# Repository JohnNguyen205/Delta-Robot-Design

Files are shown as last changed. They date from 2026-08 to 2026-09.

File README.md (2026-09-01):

# Delta Robot Design — 3-DOF Parallel Robot Mechanical Design

> **Mechanical design project** — Ho Chi Minh City University of Technology and Education (HCMUTE).
> Complete mechanical design of a ceiling-mounted 3-DOF Delta parallel robot for high-speed pick-and-place, benchmarked against the ABB IRB 360 FlexPicker.

This repository contains the SolidWorks CAD model, the MATLAB analysis and simulation code, the finite-element (FEA) results, the machining drawings, and the electrical / control-system and machine-vision design. Every conclusion is backed by data read back from the model or the solver — no assumed figures. All figures below are taken from the design analysis, the FEA results and the control-system design.

---

## Overview

| | |
|---|---|
| Architecture | 3-DOF Delta (parallel), rotational actuators, ceiling-mounted |
| Payload | **2 kg** |
| Workspace | cylinder **Ø800 × 250 mm**, centred ≈ 925 mm below the shoulder plane |
| Pick-and-place cycle | 1.2 s (quintic trajectory) |
| Peak TCP speed / acceleration | ≈ 1875 mm/s / ≈ 1.18 g |
| Actuator | Wittenstein TPMA010S-055T gearmotor, ratio *i* = 55 |
| Structural material | Aluminium 6061-T6 (all machined parts) |
| Total mass | 122.4 kg (CAD model), ≈ 140 kg estimated real |
| Minimum factor of safety (whole robot, full workspace) | **7.1** |

---

## 1. Kinematic architecture

| Symbol | Meaning | Value |
|---|---|---|
| L₁ | upper-arm (bicep) length: shoulder axis → elbow ball line | 407.5 mm |
| L₂ | forearm length, ball-centre to ball-centre | 1000.0 mm |
| R | base joint-circle radius | 347.0 mm |
| r | moving-platform radius | 120.6 mm |
| R − r | base radius − moving-platform radius | 226.4 mm |
| φᵢ | arm azimuths | −90°, 30°, 150° |
| θᵢ | motor-angle range (elbow-down) | −45° … 70° |

<p align="center">
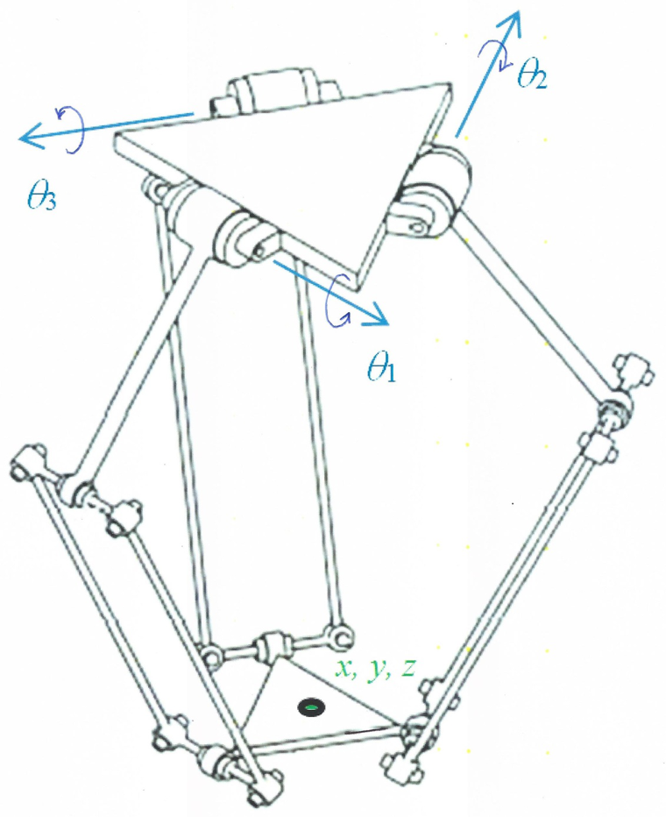
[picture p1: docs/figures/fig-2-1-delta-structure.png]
Basic structure of the RUU Delta robot
  
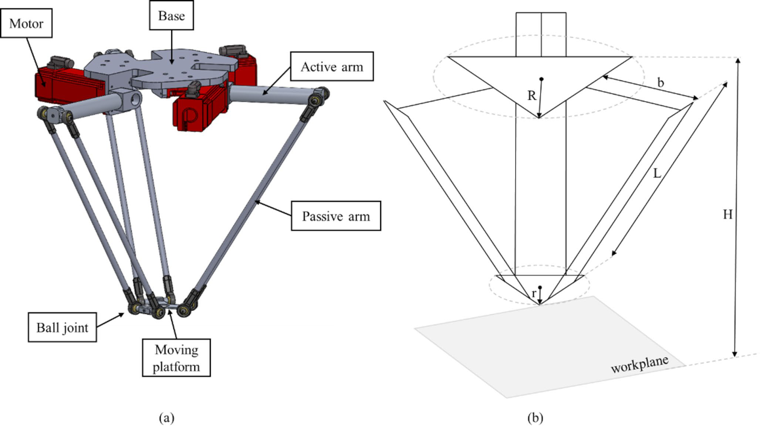
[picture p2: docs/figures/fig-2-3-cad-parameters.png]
CAD model and general geometric parameters
  
</p>

<p align="center"><b>Fig. 2.1 / 2.3.</b> Basic structure of the three-arm RUU Delta robot (left); CAD model and the general geometric parameters R, r, L, b, H (right).</p>

### Geometric model

Each arm $i$ has a fixed azimuth $\phi_i$; the three arms sit at −90°, 30° and 150°. Writing $c_i=\cos\phi_i$ and $s_i=\sin\phi_i$, and measuring the motor angle $\theta_i$ downward from the shoulder plane, the base joint, the platform joint and the elbow of arm $i$ are

$$\mathbf{B}_i = R\,(c_i,\ s_i,\ 0)$$

$$\mathbf{P}_i = \mathbf{P} + r\,(c_i,\ s_i,\ 0)$$

$$\mathbf{E}_i = \mathbf{B}_i + L_1\,(c_i\cos\theta_i,\ s_i\cos\theta_i,\ -\sin\theta_i)$$

The rigid forearm gives one closure equation per arm:

$$\lVert \mathbf{E}_i - \mathbf{P}_i \rVert = L_2$$

### Inverse kinematics (closed form)

For a target $\mathbf{P}=(x,y,z)$ the closure equation of each arm reduces to a single equation in $\theta_i$:

$$E_i\sin\theta_i + F_i\cos\theta_i + G_i = 0$$

$$u_i = x\,c_i + y\,s_i - (R-r), \qquad w_i = -x\,s_i + y\,c_i$$

$$E_i = 2 L_1 z, \qquad F_i = -2 L_1 u_i, \qquad G_i = L_1^2 + u_i^2 + w_i^2 + z^2 - L_2^2$$

With $\rho_i=\sqrt{E_i^2+F_i^2}$ and $\psi_i=\mathrm{atan2}(F_i,\ E_i)$:

$$\theta_i = \arcsin\!\left(\frac{-G_i}{\rho_i}\right) - \psi_i$$

taking the elbow-down root inside the range −45° … 70°. A real solution exists only if $|G_i| \le \rho_i$; otherwise $\mathbf{P}$ lies outside the reachable workspace.

### Forward kinematics

Given the three angles, shift each elbow to a virtual centre $\mathbf{C}_i = \mathbf{E}_i - r\,(c_i,\ s_i,\ 0)$. The platform centre $\mathbf{P}$ is the intersection (trilateration) of three spheres of radius $L_2$ centred at $\mathbf{C}_1,\mathbf{C}_2,\mathbf{C}_3$, keeping the lower-$z$ root. Round-trip check: the error $\lVert \mathbf{P} - \mathrm{FK}(\mathrm{IK}(\mathbf{P})) \rVert$ stays below $6.2\times10^{-13}$ mm over 3000 points (see §2).

### Velocity Jacobian and singularity

Differentiating the three closure equations gives

$$\mathbf{A}\,\dot{\mathbf{P}} = \mathbf{B}\,\dot{\boldsymbol{\theta}}, \qquad \dot{\mathbf{P}} = \mathbf{J}\,\dot{\boldsymbol{\theta}}, \qquad \mathbf{J} = \mathbf{A}^{-1}\mathbf{B}$$

Row $i$ of $\mathbf{A}$ is the forearm direction $(\mathbf{E}_i-\mathbf{P}_i)^{T}$, and $\mathbf{B}$ is diagonal with

$$B_{ii} = L_1\,(\mathbf{E}_i-\mathbf{P}_i)^{T}\,\hat{\mathbf{v}}_i, \qquad \hat{\mathbf{v}}_i = (-c_i\sin\theta_i,\ -s_i\sin\theta_i,\ -\cos\theta_i)$$

Here $\det\mathbf{A}=0$ marks a parallel (Type II) singularity, $\det\mathbf{B}=0$ a boundary (Type I) singularity, and the condition number $\kappa(\mathbf{J})$ measures how close a pose is to one. Over the target workspace $\kappa(\mathbf{J}) \le 2.75$ with no singular points.

## 2. Kinematics verification

The inverse and forward kinematics were implemented independently and cross-checked:

- Round-trip error ‖P − FK(IK(P))‖ ≤ **6.2 × 10⁻¹³ mm** over 3000 sample points.
- Reachable radius 650 mm at z = −925 mm (requirement: 400 mm).
- Jacobian: **no singular points** inside the workspace; condition number κ(J) max 2.75, average 2.13; minimum forearm–bicep transmission angle 49.8°.

<p align="center">
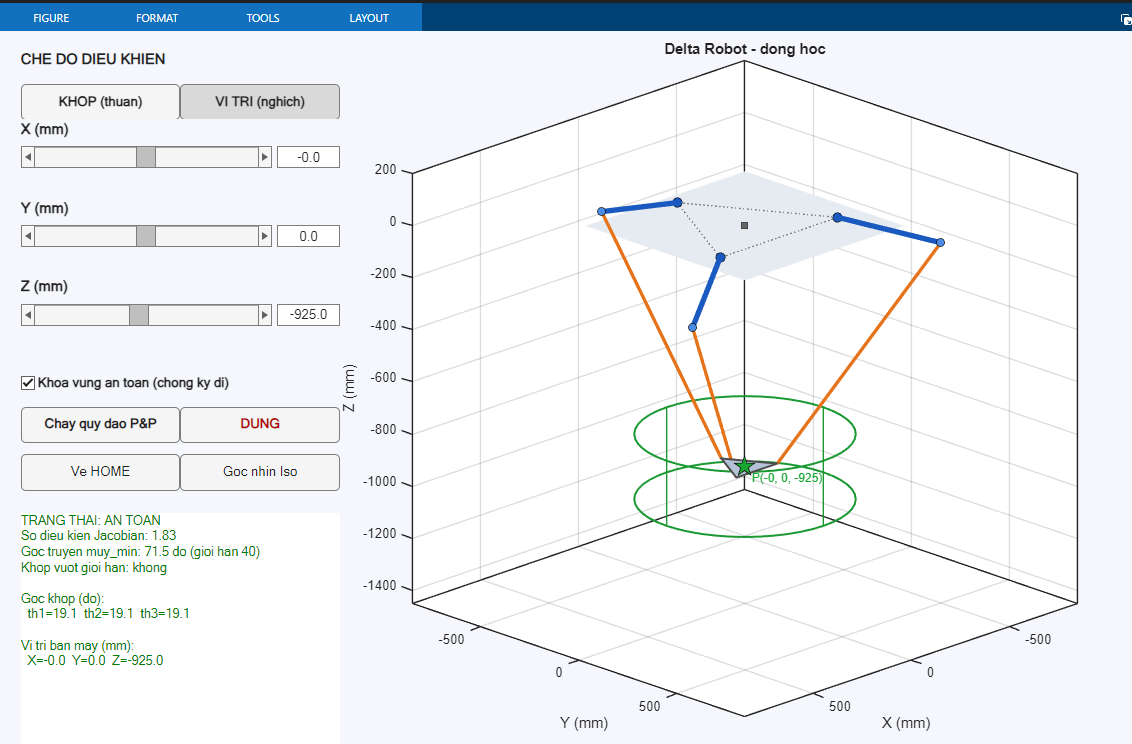
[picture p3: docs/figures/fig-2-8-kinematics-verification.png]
Simulation check of the kinematic solution
  
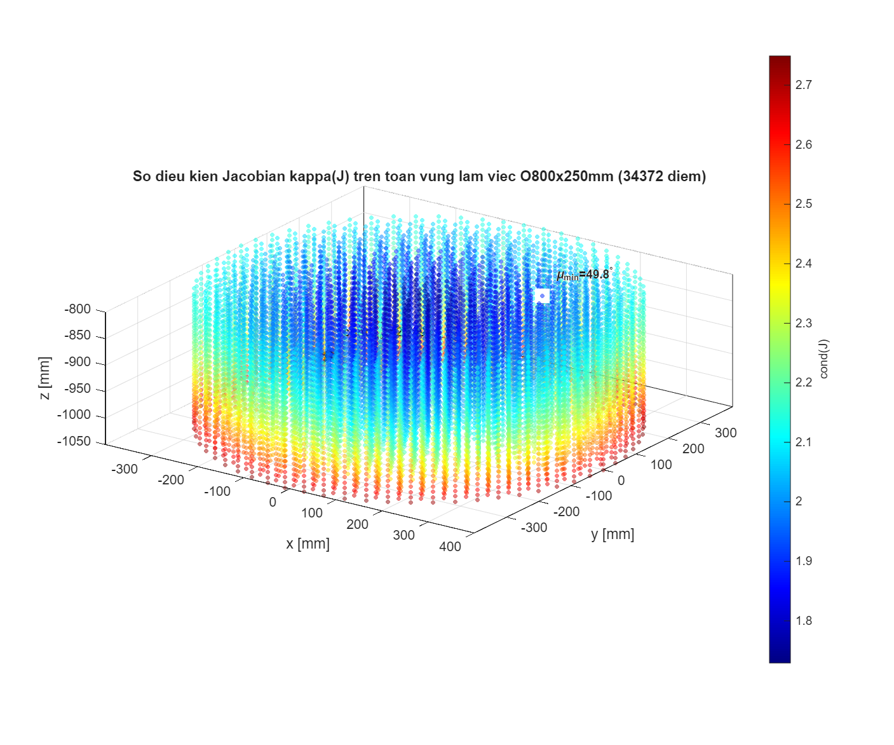
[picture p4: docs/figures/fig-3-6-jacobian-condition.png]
Jacobian condition number and transmission angle
  
</p>

<p align="center"><b>Fig. 2.8 / 3.6.</b> Simulation check of the kinematic computation (left); distribution of the Jacobian condition number and the force-transmission angle over the working region (right).</p>

<p align="center">
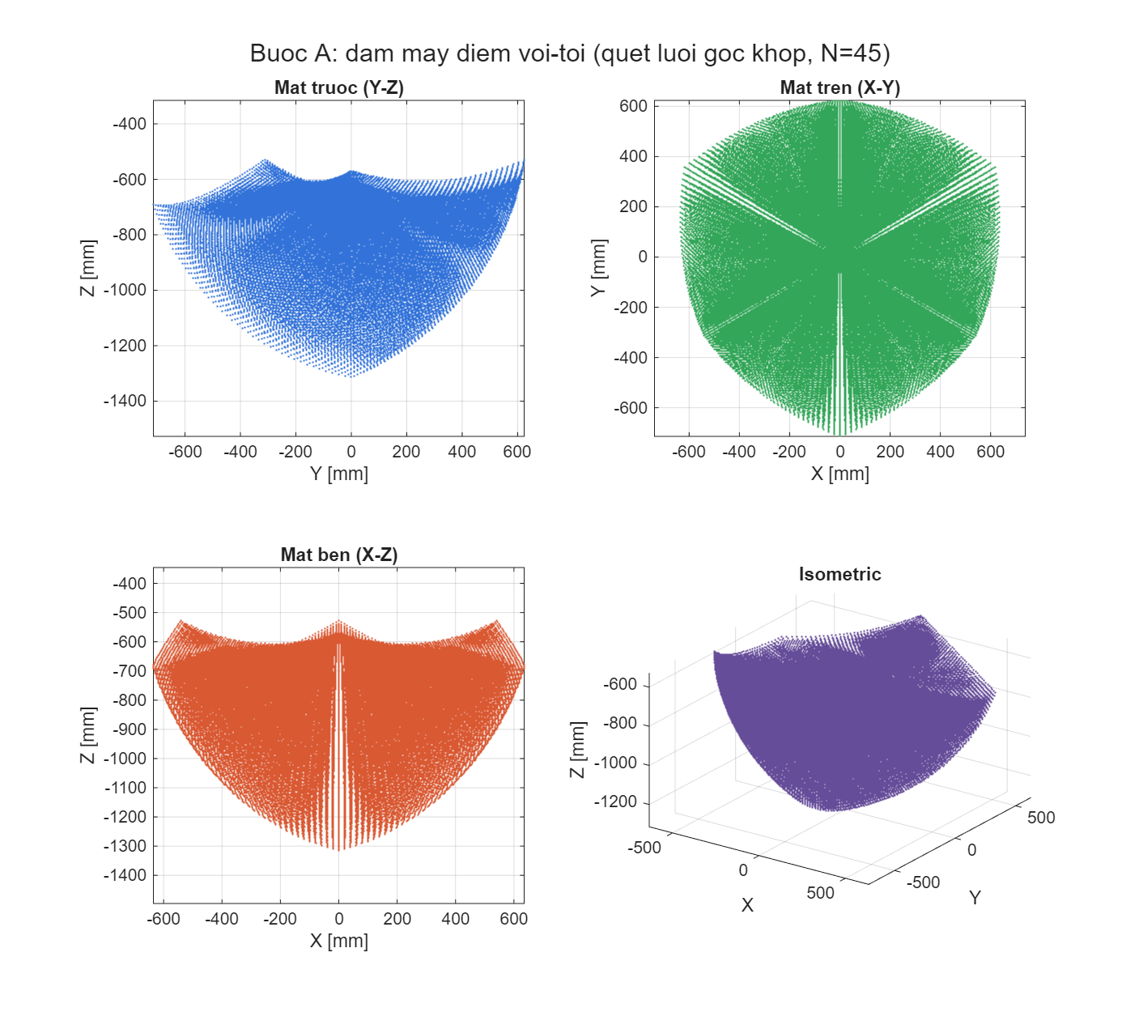
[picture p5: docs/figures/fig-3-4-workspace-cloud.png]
Workspace point cloud
  
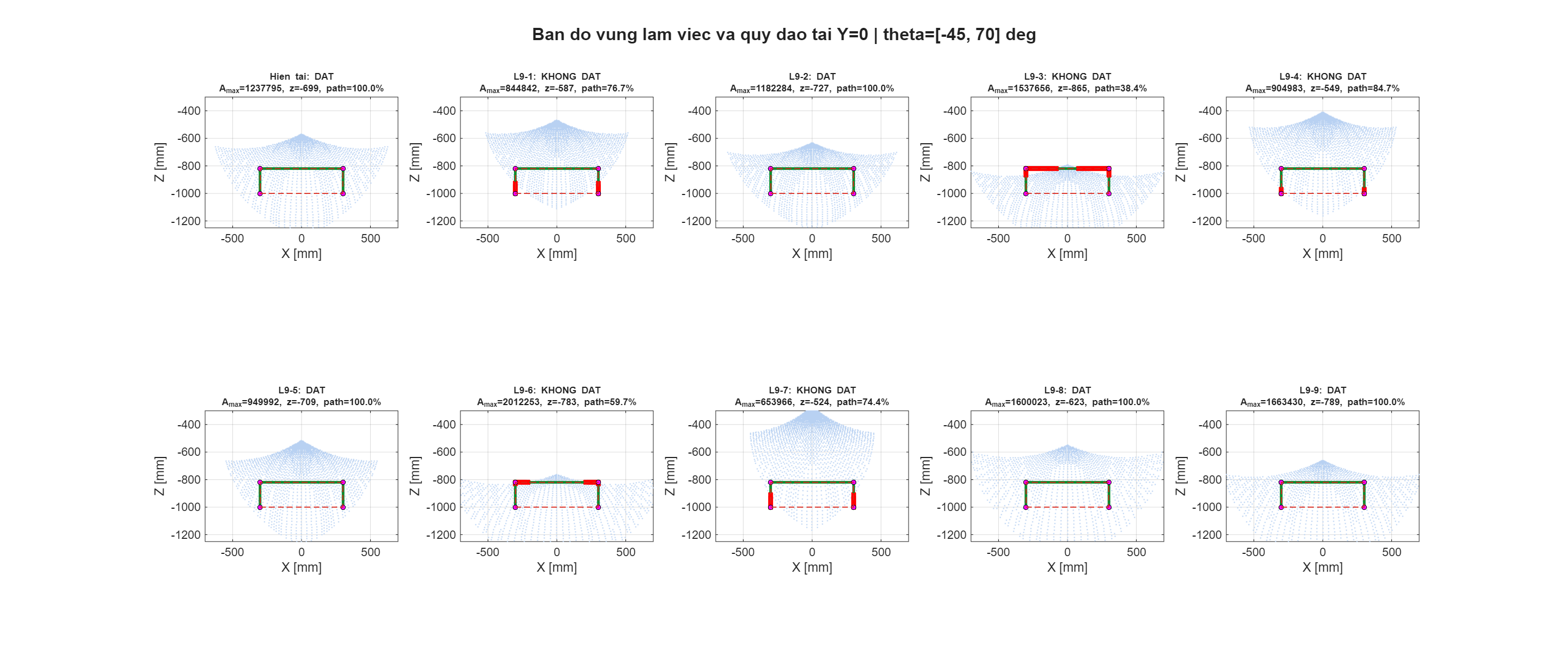
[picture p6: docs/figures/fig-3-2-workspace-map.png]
Workspace map at y = 0 with trajectory check
  
</p>

<p align="center"><b>Fig. 3.4 / 3.2.</b> Workspace point cloud from the three joint-angle sweep (left); workspace map at y = 0 with the pick-and-place trajectory check (right).</p>

## 3. Motion & trajectory

The pick-and-place cycle is planned as a fifth-order (quintic) polynomial and the joint kinematics are checked against their bounds.

<p align="center">
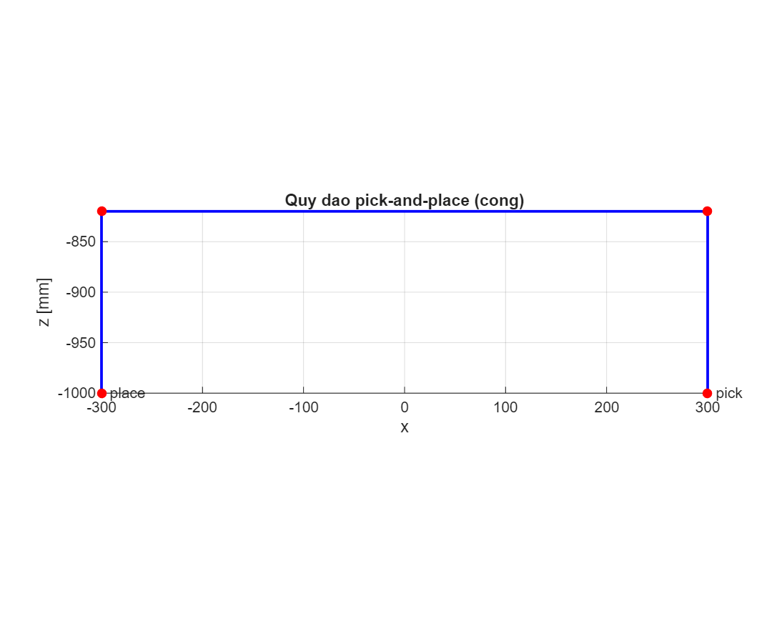
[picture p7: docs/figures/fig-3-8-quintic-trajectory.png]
Quintic pick-and-place trajectory
  
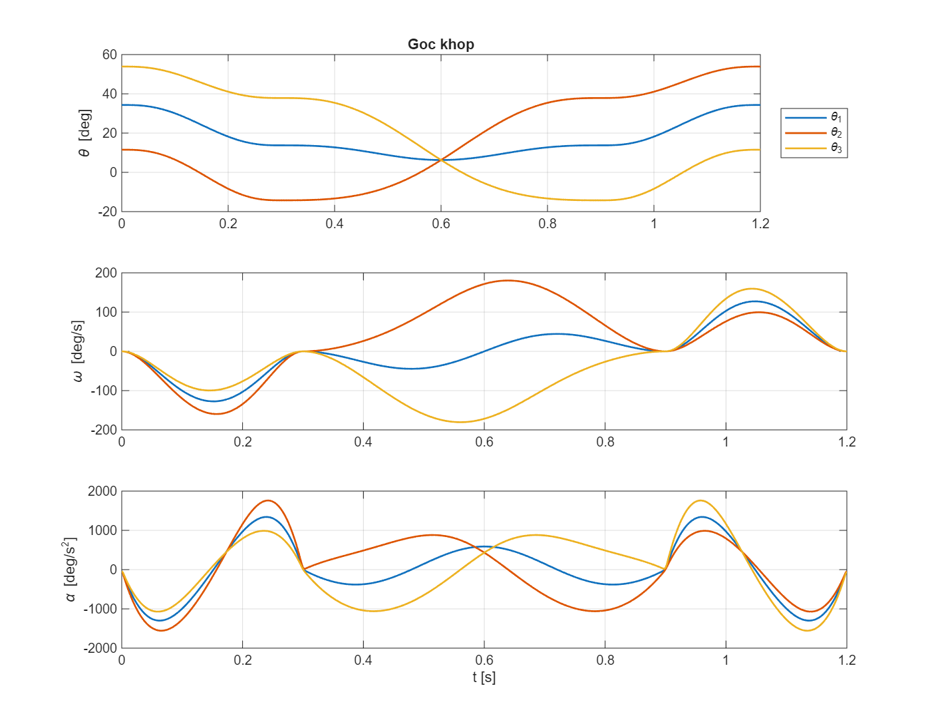
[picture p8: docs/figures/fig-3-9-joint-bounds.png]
Joint angle, velocity and acceleration bounds
  
</p>

<p align="center"><b>Fig. 3.8 / 3.9.</b> Pick-and-place trajectory interpolated with a fifth-order polynomial (left); joint angle, angular-velocity and angular-acceleration bounds along the trajectory (right). Peak joint speed 30.1 rpm.</p>

## 4. Force & dynamic analysis

Forearm links are solved as two-force members; joint torques are obtained through the Jacobian. Loads are swept over the whole workspace (centre + 24 edge points + 4 waypoints × 26 peak-acceleration directions) and the worst case is retained.

| Quantity | Nominal (centre pose) | Worst case (workspace edge, R400 / z−1050) |
|---|---|---|
| End-effector force F_ee | 175.8 N | 176.1 N |
| Forearm-pair force | 122.7 N (61.3 N per rod) | **182.4 N** (× 1.49) |
| Bicep bending moment | ≈ 50 N·m | **74.3 N·m** (× 1.49) |
| Platform joint torque τ | 48.4 N·m | — |
| Jacobian condition number | — | 2.75 (no singularity) |

<p align="center">
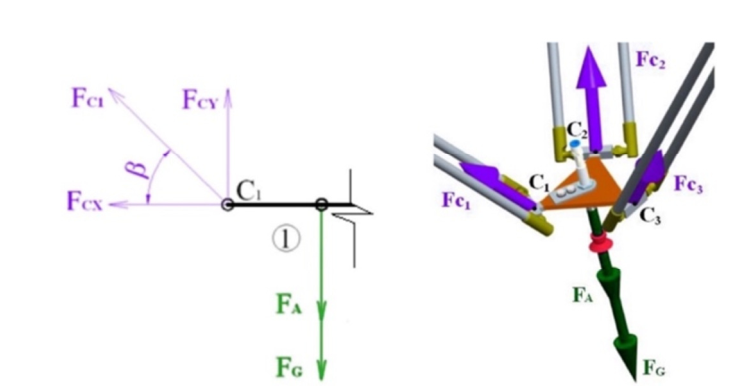
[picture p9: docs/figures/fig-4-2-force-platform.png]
Force diagram at the moving platform
  
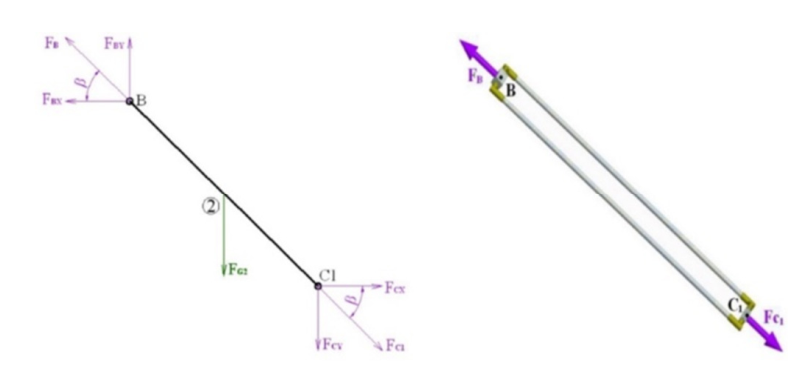
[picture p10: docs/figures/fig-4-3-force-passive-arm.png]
Force diagram of the passive arm
  
</p>

<p align="center"><b>Fig. 4.2 / 4.3.</b> Force diagram at the moving platform (left) and in the passive (long) arm (right).</p>

<p align="center">
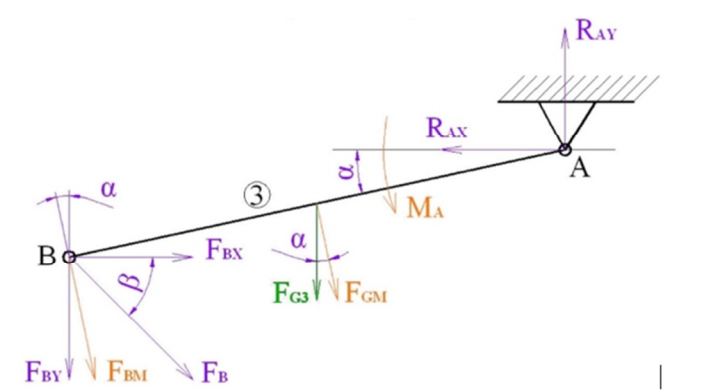
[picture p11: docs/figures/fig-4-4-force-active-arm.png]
Force diagram of the active arm
  
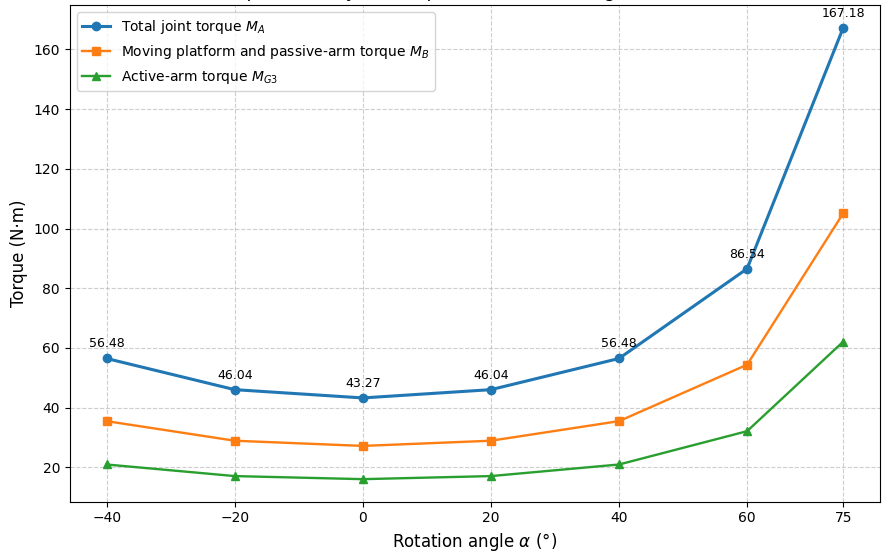
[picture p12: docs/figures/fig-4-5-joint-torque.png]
Active-joint torque versus tilt angle
  
</p>

<p align="center"><b>Fig. 4.4 / 4.5.</b> Force diagram of the active arm (left); torque at the active joint versus tilt angle α (right).</p>

## 5. Actuator selection

The required joint torque is split into static and dynamic terms and multiplied by a 1.5 safety factor (per the advisor's method), including the bicep weight and inertia (6.9 kg, from CAD) and the reflected rotor inertia *J*₍mot₎·*i*²:

| Criterion | Result | Margin |
|---|---|---|
| Required torque M_yc = (M_static 35.8 + M_dynamic 55.0) × 1.5 | 136.3 N·m ≤ T2B 230 N·m | **1.69 ×** |
| RMS torque M_rms | 53.4 N·m ≤ 110 N·m | **2.06 ×** |
| Joint speed | 30.1 rpm ≤ 88 rpm | pass |

The initially considered TPM-010S-061T (T2B 80 N·m) is rejected — M_yc 112.5 N·m > 80 N·m. The high-torque **TPMA010S-055T** passes all three criteria.

<p align="center">
  Selected gearmotor TPMA010S-055T
</p>

<p align="center"><b>Fig. 4.6.</b> Selected gearmotor with reduction unit — Wittenstein TPMA010S-055T.</p>

## 6. Structure & materials

- **All machined parts: aluminium 6061-T6.** The base was first designed in ASTM A36 steel but was too heavy, so all three base blocks were reassigned to 6061-T6 (−128.8 kg).
- Forearm connecting rods: carbon fibre. Ball-joint rod ends (`60645K471`): alloy steel.
- The base plate (`DR-001`) is split into three separate fabrication blocks — mounting plate, welded frame, and hanging lid — bolted/welded together.
- Part numbering: `DR-000` main assembly, `DR-001…DR-007` machined parts; purchased parts keep their vendor names.

<p align="center">
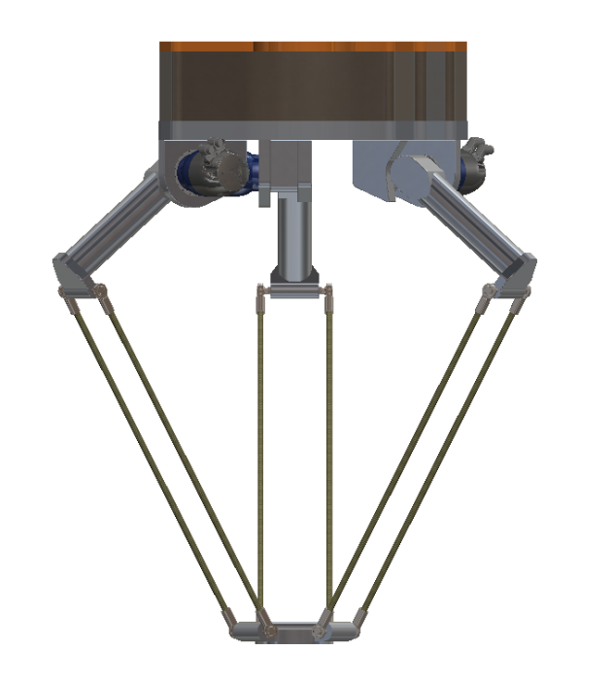
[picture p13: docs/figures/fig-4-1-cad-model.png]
3D design model in SolidWorks
  
</p>

<p align="center"><b>Fig. 4.1.</b> 3D design model in SolidWorks.</p>

## 7. Vacuum gripper (end effector)

The end effector is a vacuum gripper at the platform centre, facing down, that
picks parts off the conveyor and sorts them by shape (triangle / circle /
square). The cup, valve, tubing and sensor mass is **not** part of the 2 kg
payload — it is added to the dynamic model once the hardware is fixed; the grip
is sized against the 2 kg payload alone.

Required suction force (weight + lift inertia, with a pull-off safety factor):

$$F_s = k\,m\,(g + a_z)$$

Total cup area and minimum working vacuum for $n$ round cups of diameter $d$ and
effective efficiency $\eta$:

$$S = n\,\pi\,\frac{d^{2}}{4}, \qquad p_\text{req} = \frac{F_s}{\eta\,S}, \qquad F_\text{cap} = \eta\,p_\text{max}\,S \ge F_s$$

With $k = 2.0$, $m = 2.0$ kg, $g = 9.81$, $a_z = 11.58$ m/s², $n = 2$ cups,
$d = 40$ mm, $\eta = 0.70$:

| Quantity | Value |
|---|---|
| Required suction force $F_s$ | 85.56 N |
| Total cup area $S$ | 2.513 × 10⁻³ m² |
| Minimum vacuum $p_\text{req}$ | 48.7 kPa |
| Holding force at $p_\text{max}=60$ kPa | 105.6 N ≥ 85.56 N ✓ |

Preliminary cup layout by shape: triangle 2 × Ø40 (or 4 × Ø30), circle 2 × Ø40
symmetric about the centre, square 4 × Ø30.

<p align="center">
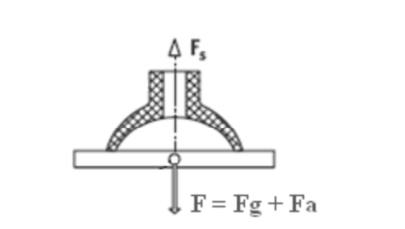
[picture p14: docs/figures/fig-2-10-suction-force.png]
Force diagram of a part lifted vertically by a vacuum cup
  
</p>

<p align="center"><b>Fig. 2.10.</b> Forces on a part lifted vertically by the vacuum cup: suction force F<sub>s</sub> up, weight + lift inertia F = F<sub>g</sub> + F<sub>a</sub> down.</p>

## 8. Structural validation (FEA)

SolidWorks Simulation, static studies on the load-bearing parts with the peak dynamic loads from §4, including a mesh-convergence sweep and a full-workspace multi-pose sweep.

| Part | von Mises (worst pose) | Factor of safety |
|---|---|---|
| DR-006 Elbow clevis | 38.8 MPa | **7.1** (governing) |
| DR-005-2 Upper-arm link | — | 43.5 |
| DR-007 Moving platform | — | 14.7 |
| DR-001-1 Base plate (aluminium) | — | ≈ 1268 |
| DR-001-3 Ceiling lid (aluminium) | — | ≈ 72 |

<p align="center">
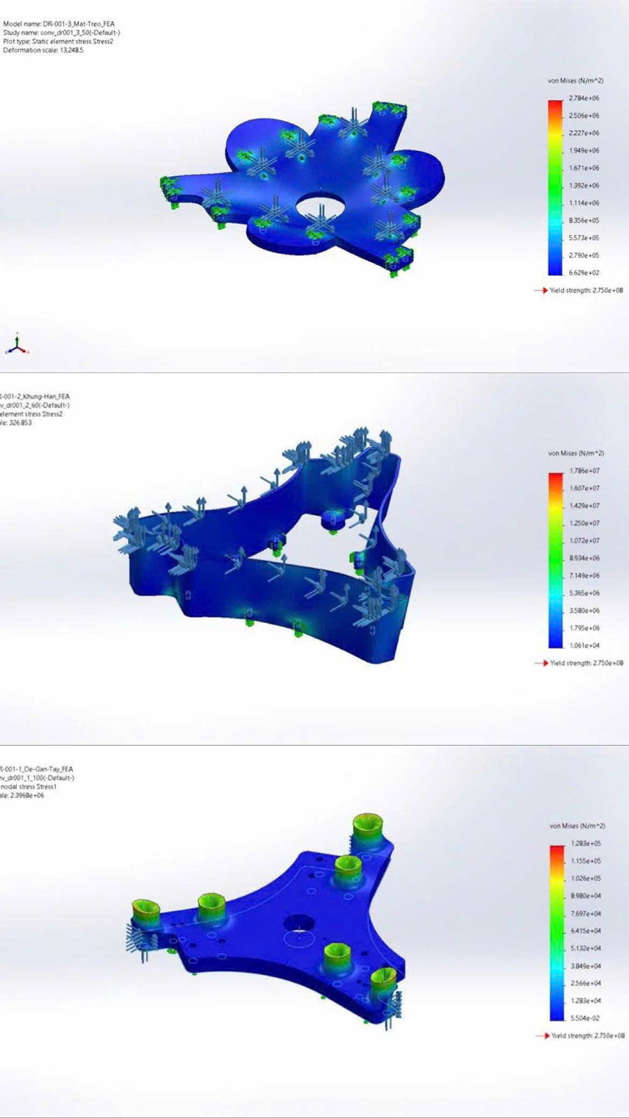
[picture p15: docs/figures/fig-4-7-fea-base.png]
von Mises stress on the base blocks
  
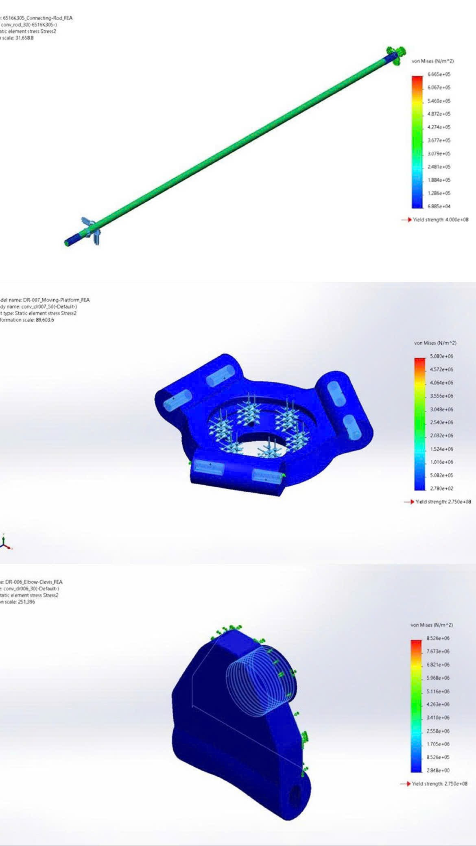
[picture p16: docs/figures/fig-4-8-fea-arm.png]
von Mises stress on the arm parts and rod
  
</p>

<p align="center"><b>Fig. 4.7 / 4.8.</b> von Mises stress — DR-001-3, DR-001-2 and DR-001-1 (left); DR-006, DR-007 and connecting rod 6516K305 (right). The whole-robot minimum factor of safety over the entire workspace is <b>7.1</b>.</p>

---

## 9. Electrical & control system

The control system is a Siemens motion-control stack. An industrial PC (**SIMATIC IPC**) runs the vision pipeline and streams pick coordinates over **PROFINET** to a **SIMOTION D** motion controller, which carries a built-in Delta technology object (synchronous three-axis interpolation). SIMOTION drives three **SINAMICS S120** motor modules over **DRIVE-CLiQ**, one per arm, each powering a **TPMA010S-055T** gearmotor with incremental-encoder feedback. The three motor modules share one Active Line Module (common DC bus), so braking energy is recovered between axes.

Safety is a hardwired chain independent of the main controller: an E-Stop / limit-switch loop (Siemens 3RG40 / SIRIUS 3SK) triggers **STO** (Safe Torque Off, IEC 61800-5-2) directly on the SINAMICS drives through a SIRIUS 3SK safety relay.

Servo power is **320 V AC** (per the TPMA010S-055T datasheet); SIMOTION, the SIRIUS relay and the IPC share a **24 V DC** control supply (IEC 61131-2); the camera is powered over its GigE link. DC-supply and fuse ratings, and the conveyor branch, are not yet dimensioned.

| Link | Bus / standard | Purpose |
|---|---|---|
| Camera (Basler acA1300-30gc) ↔ SIMATIC IPC | GigE Vision (Ethernet ≤ 1000 Mbps) | raw high-speed image transfer |
| SIMATIC IPC ↔ SIMOTION D | PROFINET IO (real-time industrial Ethernet) | pick coordinates / status |
| SIMOTION D ↔ SINAMICS S120 (×3) | DRIVE-CLiQ (internal bus, same rack) | servo control, real-time encoder feedback |
| SIRIUS 3SK ↔ SINAMICS S120 | STO (IEC 61800-5-2, hardwired) | controller-independent safe torque off |
| E-Stop / limit switch (3RG40) ↔ SIRIUS 3SK | hardwired digital I/O | safety signal |
| SINAMICS S120 ↔ TPMA010S-055T (×3) | power cable + incremental-encoder cable | servo power, position feedback |
| AC mains ↔ SINAMICS S120 | 320 V AC | drive power |
| DC supply ↔ IPC / SIMOTION / SIRIUS | 24 V DC | control power |

<p align="center">
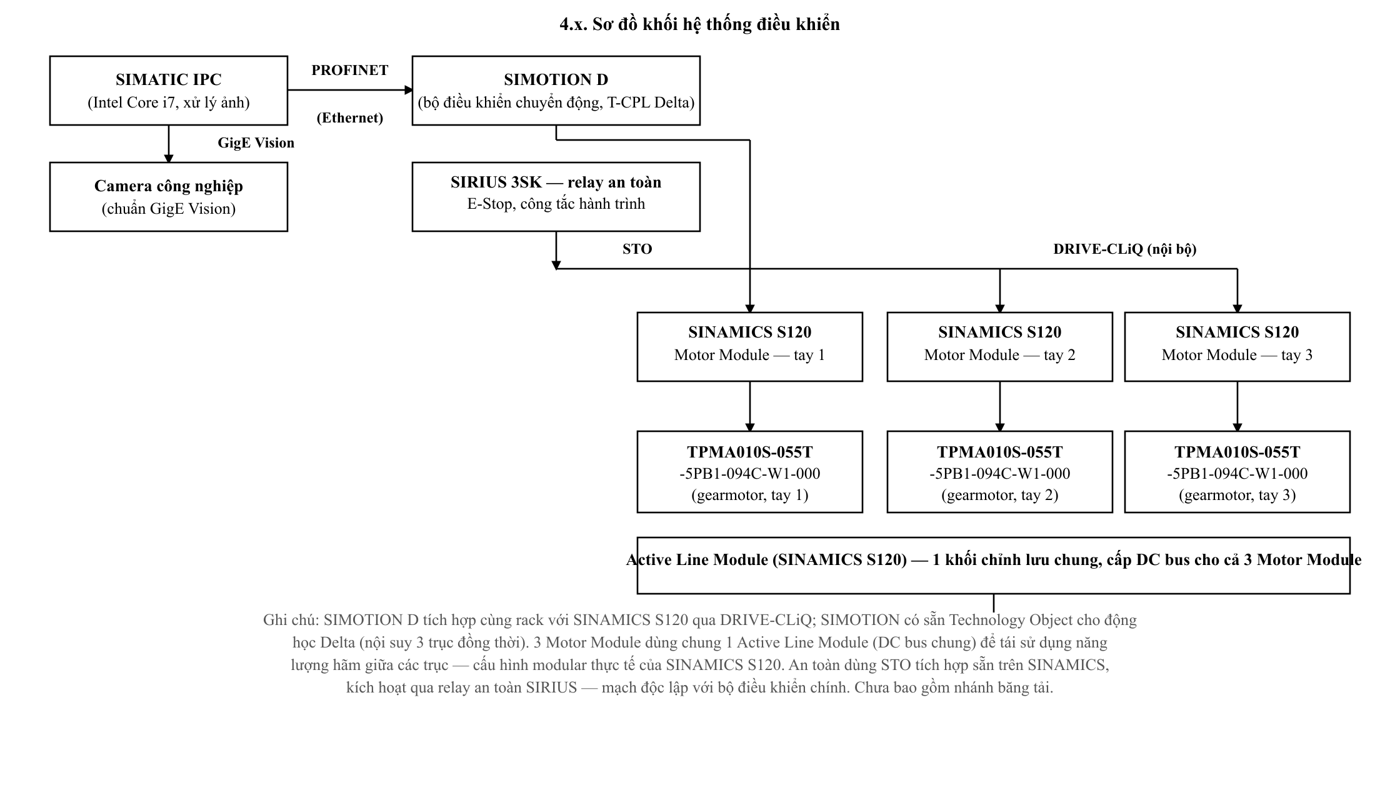
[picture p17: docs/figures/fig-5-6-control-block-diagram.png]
Control system block diagram
  
</p>

<p align="center"><b>Fig. 5.6.</b> Control-system block diagram — vision IPC, SIMOTION D motion controller, three SINAMICS S120 drives on a shared DC bus, and the SIRIUS / STO safety branch.</p>

<p align="center">
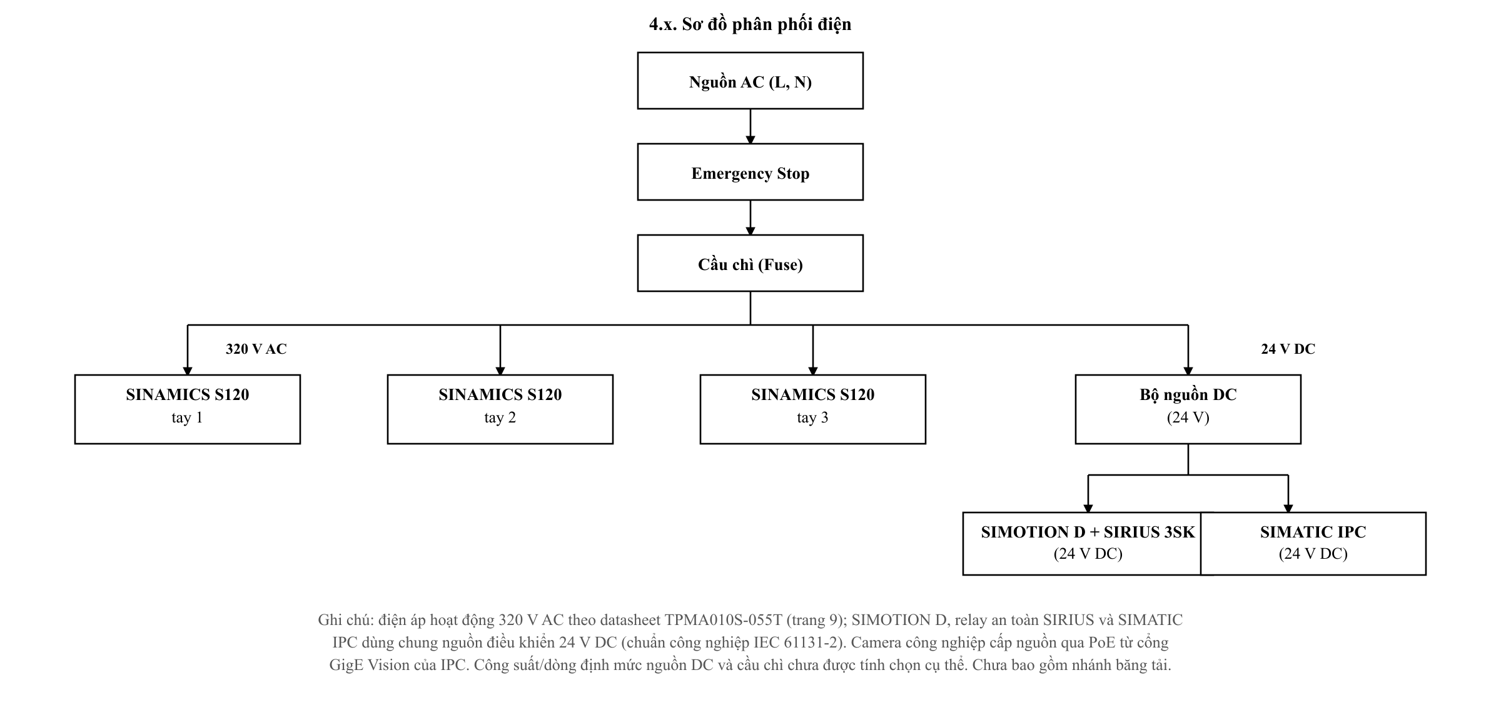
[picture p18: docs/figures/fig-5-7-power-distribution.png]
Power distribution diagram
  
</p>

<p align="center"><b>Fig. 5.7.</b> Power distribution — AC mains through E-Stop and fuse to 320 V AC for the three drives and a 24 V DC control supply for the IPC, SIMOTION D and SIRIUS relay.</p>

## 10. Machine vision (image processing)

Each frame is converted from BGR to HSV, then two branches run in parallel. The **shape** branch performs corner / blob detection and template matching, classifying every object as circle, square or triangle. The **colour** branch applies fixed HSV thresholds for red, green and yellow and detects blobs by area. The two results are merged into a `(colour, shape)` label per object, and the corresponding pick coordinate is sent to the IPC.

| Colour | Lower (H, S, V) | Upper (H, S, V) |
|---|---|---|
| Red | (173, 0, 0) | (255, 255, 255) |
| Yellow | (18, 0, 76) | (36, 255, 255) |
| Green | (58, 155, 114) | (85, 255, 255) |

On a synthetic test image of 9 objects (3 shapes × 3 colours) on a dark, conveyor-like background, the algorithm returned the correct `(colour, shape)` label for **all 9**, and the red threshold isolated a clean binary mask containing only the 3 red objects — confirming the pipeline before integration with a real camera.

A pixel coordinate (u, v) is mapped to a physical pick point (X, Y) through three coordinate frames — camera {C}, robot base {B} and conveyor {W} — by a linear calibration.

<p align="center">
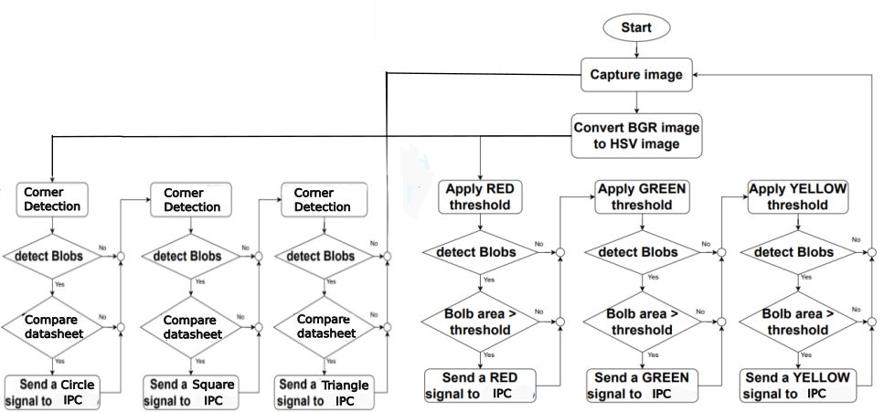
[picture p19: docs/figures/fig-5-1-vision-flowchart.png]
Colour and shape recognition flowchart
  
</p>

<p align="center"><b>Fig. 5.1.</b> Colour- and shape-recognition algorithm: parallel shape branch (corner / blob detection, template match → circle / square / triangle) and colour branch (HSV threshold → red / green / yellow, blob by area).</p>

<p align="center">
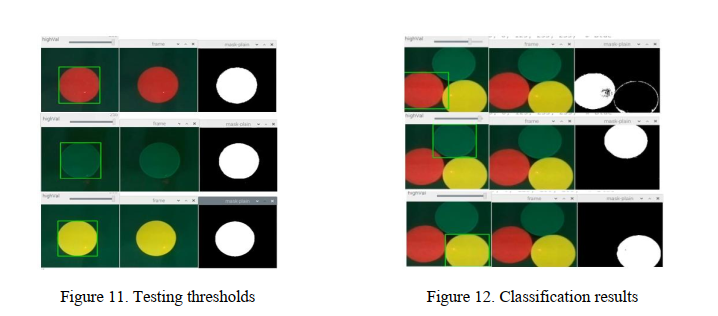
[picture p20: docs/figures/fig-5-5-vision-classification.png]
Threshold tuning and multi-object classification result
  
</p>

<p align="center"><b>Fig. 5.5.</b> Threshold tuning per colour (left) and the resulting multi-object classification on the simulated conveyor image (right).</p>

---

## 11. Design report — chapters

| Chapter | Title | What it covers |
|---|---|---|
| **1** | Overview | Motivation; state of the art of Delta robots; general and specific objectives; research object and scope; research method; report outline. |
| **2** | Theoretical basis | Delta structure and working principle; geometric model and coordinate frames; kinematic foundations — degrees of freedom, geometric parameters, per-limb closed-loop equations, forward kinematics, inverse kinematics, model-consistency check; basis for the vacuum-gripper design — joint layout and suction-cup arrangement, suction force and vacuum pressure. |
| **3** | Workspace computation & simulation | Objectives, scope and input data; the L9 survey parameter set and the test trajectory; point-density workspace simulation — joint-space sweep, volume and largest-cross-section estimate; verification of the target Ø800 × 250 mm cylinder, of the pick-and-place trajectory, and of the joint velocity / acceleration bounds. |
| **4** | Load analysis, material & drivetrain selection | Material selection; part masses from CAD; load data and force-distribution model; internal-force analysis of the links — free-body model, axial forces, motor–gearbox selection; FEA strength check of the main load-bearing parts; overall strength summary versus requirements. |
| **5** | Electrical & control system design | Machine-vision system — colour/shape recognition algorithm and test results on sample images; camera–robot–conveyor coordinate transforms; control-board architecture. |
| **6** | Conclusion & future work | Results, limitations of the work, and development directions. |

---

<sub>The full design report, third-party vendor CAD and reference papers are not included in this repository (see `.gitignore`). All rights reserved; please cite if reused. © JohnNguyen205, HCMUTE.</sub>

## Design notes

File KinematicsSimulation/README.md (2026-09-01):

# Kinematics simulation — Delta Robot (MATLAB R2025a)

Self-contained inverse/forward kinematics, workspace, singularity and trajectory
study for the 3-DOF Delta robot. All kinematic constants come from `params.m`
(single source) and must stay in sync with the CAD design values.

## Contents

| File | Purpose |
|---|---|
| `params.m` | kinematic constants: `L1=407.5`, `L2=1000.0`, `R=347.0`, `r=120.6` mm, `phi=(-90,30,150)°` |
| `delta_ik.m` / `delta_fk.m` | inverse (P → θ, closed form) / forward (θ → P, trilateration) kinematics |
| `delta_jacobian.m` | velocity Jacobian `J = A⁻¹B`, condition number, transmission angle, Type I/II singularity flags |
| `p3_workspace.m` | joint-sweep workspace point cloud + volume / largest cross-section |
| `p4_singularity.m`, `p4b_cond3d.m` | κ(J) map over the working region |
| `p5_trajectory.m` | quintic pick-and-place trajectory, joint bound check |
| `p6_animate.m`, `delta_gui.m`, `deltaviz.m` | animation and interactive viewer |
| `verify_target_workspace.m` | check the Ø800 × 250 mm target cylinder is fully reachable |
| `THUYETMINH_DONGHOC_CHITIET.md`, `TINHTOAN_DONGHOC_CHITIET.md` | detailed derivation and worked calculation (Vietnamese) |
| `KETQUA_DONGHOC.md` | phase-by-phase results log |
| `figs/`, `out/` | generated figures / logs / `.mat` |

## How to run

```
matlab -batch "cd('<repo>/KinematicsSimulation'); test_p1_ik_fk"
matlab -batch "cd('<repo>/KinematicsSimulation'); p3_workspace"
matlab -batch "cd('<repo>/KinematicsSimulation'); p5_trajectory"
```

`delta_gui.m` renders only on the live MATLAB desktop, not in `-batch`.

## Key results

- FK(IK(P)) round-trip error ≤ 6.2 × 10⁻¹³ mm over 3000 points.
- Reachable radius 650 mm at z = −925 mm (requirement 400 mm).
- Jacobian: no singular points in the workspace; κ(J) max 2.75, avg 2.13;
  minimum forearm–bicep transmission angle 49.8°.

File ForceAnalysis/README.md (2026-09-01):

# Force analysis & actuator selection — Delta Robot (payload 2 kg)

Force study that (1) produces the **real loads** used as FEA input and
(2) **checks the gearmotor choice** by the static + dynamic × safety-factor
moment method (advisor's format): forearm links solved as two-force members,
joint torques through the Jacobian, motor sizing including bicep weight/inertia
(6.9 kg from CAD) and reflected rotor inertia `J_mot·i²`, safety factor 1.5.

## Contents

| File | Purpose |
|---|---|
| `params.m`, `delta_ik.m`, `delta_jacobian.m` | kinematic constants + IK/Jacobian (copy kept in sync with `../KinematicsSimulation`) |
| `force_analysis.m` | forearm forces + static/dynamic joint moments + motor–gearbox check |
| `force_poses.m` | multi-pose load sweep (centre + 24 workspace-edge points + waypoints × peak-accel dirs), worst case retained |
| `force_diagrams.m` | free-body diagram + N/Q/M internal-force diagrams |
| `moment_angle_sweep.m` | joint moment vs tilt angle, CSV/MAT + peak plot |
| `fea_load_params.m` | exports the peak loads consumed by `../FEA_Simulation` |
| `ThuyetMinh_ChonDongCo.md` | detailed motor-selection write-up (Vietnamese) |
| `figs/`, `out/` | result figures / logs / `.mat` |

## How to run

```
matlab -batch "cd('<repo>/ForceAnalysis'); force_analysis"
matlab -batch "cd('<repo>/ForceAnalysis'); force_poses"
matlab -batch "cd('<repo>/ForceAnalysis'); force_diagrams"
```

## Key results

| Quantity | Nominal (centre) | Worst case (edge, R400 / z−1050) |
|---|---|---|
| End-effector force F_ee | 175.8 N | 176.1 N |
| Forearm-pair force | 122.7 N (61.3 N/rod) | 182.4 N (× 1.49) |
| Bicep bending moment | ≈ 50 N·m | 74.3 N·m (× 1.49) |
| Jacobian condition number | — | 2.75 (no singularity) |

Motor check (TPMA010S-055T, i = 55): required M_yc = (35.8 + 55.0) × 1.5 =
136.3 N·m ≤ T2B 230 (1.69×); M_rms 53.4 ≤ 110 (2.06×); 30.1 rpm ≤ 88 rpm —
all pass. The initially considered TPM-010S-061T (T2B 80 N·m) fails.

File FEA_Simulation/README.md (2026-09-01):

# Structural simulation (FEA) — Delta Robot

SolidWorks Simulation static studies on the load-bearing parts, driven over COM
from PowerShell. Loads are the peak dynamic forces from `../ForceAnalysis`
(payload 2 kg). Each study includes a mesh-convergence sweep; a second pass
applies the worst-case multi-pose loads over the whole workspace.

## Contents

| File | Purpose |
|---|---|
| `fea_common.ps1` | shared helper (loads the compiled `SwSim` / `SwGeom` / `SwFea` classes) |
| `fea_run.ps1` | run one part: restraints, force, mesh sweep, solve, export fringe PNG |
| `run_parts.ps1` | batch wrapper over all parts (single-pose loads) |
| `run_parts_pose.ps1` | batch wrapper with the worst-case multi-pose loads (× 1.49) |
| `fea_run_v2.ps1`, `run_parts_v2.ps1` | studies embedded into `_FEA` part copies |
| `KETQUA_BEN.md` | single-pose results summary (Vietnamese) |
| `KETQUA_BEN_DAPOSE.md` | multi-pose (full-workspace) results (Vietnamese) |
| `THUYETMINH_MOPHONG_BEN_CHITIET.md` | detailed method + boundary conditions |
| `figs/`, `out/` | von Mises fringe PNGs / convergence CSVs / face-index dumps |

## How to run

```
powershell -ExecutionPolicy Bypass -File run_parts.ps1
powershell -ExecutionPolicy Bypass -File run_parts_pose.ps1
```

Do **not** call `fea_run.ps1` directly with array arguments via `powershell -File`
— commas get stripped; always go through `run_parts*.ps1`.

## Key results

| Part | von Mises (worst pose) | Factor of safety |
|---|---|---|
| DR-006 Elbow clevis | 38.8 MPa | 7.1 (governing) |
| DR-005-2 Upper-arm link | — | 43.5 |
| DR-007 Moving platform | — | 14.7 |
| DR-001-1 Base plate (Al 6061-T6) | — | ≈ 1268 |
| DR-001-3 Ceiling lid (Al 6061-T6) | — | ≈ 72 |

Whole-robot minimum factor of safety over the entire workspace: **7.1**.
Peak von Mises is mesh-sensitive at unfilleted load holes (numerical
singularities); stress / FOS is the primary output, displacement secondary.

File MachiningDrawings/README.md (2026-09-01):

# Machining drawings — Delta Robot

Fabrication drawings for the 8 machined parts (purchased parts are not drawn).
Each part has a `.SLDDRW` (editable) and a `.pdf` (for printing / submission).
The current set is **V7**, in `BanVe_ChinhSua_V7/`.

## Drawing standard

- A3 landscape, millimetres, first-angle projection (TCVN / ISO).
- Four views per sheet: three orthographic + one 3D isometric, all at one common
  scale on a fixed 2 × 2 grid.
- Drawing area kept clear of the title block; no leader / text / geometry crosses
  the border.
- Dimensions on the primary view only; the other views stay clean for reference.
- DR-001-x, DR-004 and DR-007 carry a note block for hole spec / PCD and general
  tolerances; freeform surfaces take the 3D model as the machining master.

| Drawing | Part | Common scale |
|---|---|---:|
| DR-001-1 / -2 / -3 | mounting plate / welded frame / hanging lid | 1:10 |
| DR-002 | Motor bracket A | 1:4 |
| DR-003 | Motor bracket B | 1:4 |
| DR-004 | Shoulder bracket | 1:1 |
| DR-005-1 | Upper-arm hub | 1:4 |
| DR-005-2 | Upper-arm link | 1:5 |
| DR-006 | Elbow clevis | 1:4 |
| DR-007 | Moving platform | 1:4 |

## Regeneration

Source scripts: `make_drawing2.ps1` (V6) and `BanVe_ChinhSua_V7/make_drawing_v7.ps1`
(V7), driven over COM. They read material / mass from the live part in
`DeltaRobot_Final/`, rebuild the border, four views and title block, then export
`.SLDDRW` + `.pdf`.

Check report: `BanVe_ChinhSua_V7/KIEMTRA_BANVE_V7.md`.

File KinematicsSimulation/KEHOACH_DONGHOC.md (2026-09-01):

# KẾ HOẠCH MÔ PHỎNG ĐỘNG HỌC DELTA ROBOT (MATLAB)

Môi trường: MATLAB R2025a (`E:\Mathlab\bin\matlab.exe`) — có Robotics System Toolbox, Control System, Statistics, Simulink.
Thư mục dự án: `F:\DeltaRobot\KinematicsSimulation\`. Chạy: `matlab -batch "cd('F:/DeltaRobot/KinematicsSimulation'); <script>"`.

## Thông số động học (chốt từ thiết kế CAD)
| Ký hiệu | Giá trị | Ý nghĩa |
|---|---|---|
| R | 347,0 mm | bán kính vòng khớp đế (R = (R−r)+r = 226,4+120,6) |
| r | 120,6 mm | bán kính vòng khớp bàn máy |
| R−r | 226,4 mm | tham số rút gọn (thu bàn máy về 1 điểm) |
| L1 | 407,5 mm | cánh tay trên (bicep) |
| L2 | 1000,0 mm | thanh truyền (forearm, ball-to-ball) |
| φᵢ | −90°, 30°, 150° | phương vị 3 cánh tay (120° cách đều) |
| Vùng làm việc mục tiêu | Ø800 × 250 mm | trụ đồng trục, tâm ~925 mm dưới mặt vai |

Mô hình: khớp đế Bᵢ nằm trên vòng R, bicep L1 quay trong mặt phẳng đứng-hướng kính quanh trục ngang tiếp tuyến; forearm L2 nối khuỷu tới khớp bàn máy Pᵢ = P + r·[cosφᵢ, sinφᵢ, 0]. Quy ước góc θᵢ = góc bicep chúc xuống dưới mặt ngang.

## Lộ trình 7 phase (mỗi phase phải có bằng chứng mới đánh [x])

- **Phase 0 — Chuẩn bị & thông số.** `params.m` (nguồn thông số duy nhất), cấu trúc thư mục, xác nhận MATLAB.
  - *Bằng chứng:* in thông số, MATLAB chạy được.
- **Phase 1 — Động học nghịch (IK).** `delta_ik.m`: P=(x,y,z) → (θ1,θ2,θ3) kèm cờ với-tới.
  - *Bằng chứng:* tính được góc tại vị trí home + vài điểm mẫu, giá trị hợp lý.
- **Phase 2 — Động học thuận (FK) + kiểm chứng.** `delta_fk.m`: (θ1,θ2,θ3) → P (giao 3 mặt cầu). Kiểm chứng vòng lặp FK(IK(P))=P.
  - *Bằng chứng:* sai số round-trip ≤ 1e-6 mm trên ≥ 2000 điểm ngẫu nhiên; log + biểu đồ.
- **Phase 3 — Vùng làm việc (Workspace).** Quét IK trên lưới 3D, lọc theo nghiệm thực + giới hạn góc + góc truyền. Kiểm tra trụ Ø800×250 nằm trong vùng với-tới.
  - *Bằng chứng:* hình đám mây workspace + mặt cắt + trụ mục tiêu chồng lên; xác nhận trụ nằm gọn.
- **Phase 4 — Jacobian, vận tốc, điểm kỳ dị.** `delta_jacobian.m` (Jx·v = Jθ·ω). Bản đồ số điều kiện / định thức + góc truyền trên vùng làm việc.
  - *Bằng chứng:* bản đồ điều kiện, xác nhận không kỳ dị trong vùng, số điều kiện xấu nhất (đối chiếu ~3,69 thiết kế).
- **Phase 5 — Quỹ đạo pick-and-place.** Sinh quỹ đạo (đa thức bậc 5 / hình cổng adept). Tính θ(t), ω(t), α(t) theo IK + Jacobian.
  - *Bằng chứng:* đồ thị θ/ω/α theo thời gian; tốc độ/gia tốc khớp đỉnh (dữ liệu chọn động cơ-hộp số).
- **Phase 6 — Hoạt hình 3D.** Vẽ robot (đế, bicep, forearm, bàn máy) chạy theo quỹ đạo, xuất GIF + khung hình.
  - *Bằng chứng:* file hoạt hình + ảnh khung hình.
- **Phase 7 — Tổng hợp & xuất cho thuyết minh.** Gom hình có chú thích, bảng kết quả, công thức chuẩn.
  - *Bằng chứng:* thư mục `figs/` + tài liệu tóm tắt kết quả.

## Tệp
`params.m`, `delta_ik.m`, `delta_fk.m`, `delta_jacobian.m`, `test_p1_ik_fk.m`, `p3_workspace.m`, `p4_singularity.m`, `p5_trajectory.m`, `p6_animate.m`; kết quả trong `figs/`, `out/`.

## Trạng thái (đồng bộ với TIENDO.md)
- [x] Phase 0  - [x] Phase 1  - [x] Phase 2  - [x] Phase 3  - [x] Phase 4  - [x] Phase 5  - [x] Phase 6  - [x] Phase 7 — **HOÀN THÀNH TẤT CẢ**

### Kết quả đã kiểm chứng (2026-07-12)
- P0: MATLAB R2025a, `params.m` chạy tốt.
- P1+P2: home θ=[19,15°×3]; round-trip FK(IK(P)) **max 6,2e−13 mm** / 3000 điểm; **100%** trụ với-tới. (`out/p1_p2_log.txt`, `figs/p2_roundtrip_hist.png`)
- P3: bán kính với-tới tại z=−925 là **650 mm** (cần 400); z-truc [−1350,−570]; **trụ Ø800×250 nằm gọn** (0/108 biên ngoài). (`figs/p3_workspace_xz.png`, `p3_slice_z.png`)
- P4: **0 điểm kỳ dị** / 34372; số điều kiện Jacobian max **2,75** tb 2,13; góc forearm-bicep min **49,8°**. (`figs/p4_cond_map.png`)
  - *Lưu ý quy ước:* số 3,69 và 34,6° trong ghi chú thiết kế cũ dùng định nghĩa khác (Jacobian chuẩn hóa / định nghĩa góc truyền khác); kết luận (không kỳ dị, điều kiện tốt) không đổi.
- P5: quỹ đạo pick&place (chu kỳ 1,2 s) 100% với-tới; tốc độ khớp đỉnh **30 rpm**, gia tốc **1761 deg/s²**; TCP 1875 mm/s (1,18 g). (`figs/p5_path.png`, `p5_joint_profiles.png`, `out/p5_traj.mat`)
- P6: hoạt hình 3D 49 frame → `figs/p6_animation.gif`.
- P7: tổng hợp `KETQUA_DONGHOC.md` (công thức chuẩn (1)–(3), bảng kết quả, danh mục hình).

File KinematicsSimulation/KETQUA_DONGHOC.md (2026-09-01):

# KẾT QUẢ MÔ PHỎNG ĐỘNG HỌC DELTA ROBOT (MATLAB R2025a)

Tổng hợp cho thuyết minh. Nguồn: `KinematicsSimulation/`. Thông số: R=347, r=120,6, R−r=226,4, L1=407,5, L2=1000 mm; 3 cánh tay φ=[−90°,30°,150°].

## 1. Động học nghịch (Inverse Kinematics)
Với mỗi cánh tay i (phương vi φᵢ), khớp bàn máy Pᵢ = P + r·[cosφᵢ, sinφᵢ, 0]. Đặt

&nbsp;&nbsp;(1)&nbsp; uᵢ = x·cosφᵢ + y·sinφᵢ − (R−r)  
&nbsp;&nbsp;(2)&nbsp; wᵢ = −x·sinφᵢ + y·cosφᵢ

Ràng buộc |Eᵢ − Pᵢ| = L2 rút về phương trình lượng giác chuẩn:

&nbsp;&nbsp;(3)&nbsp; Eᵢ·sinθᵢ + Fᵢ·cosθᵢ + Gᵢ = 0  
&nbsp;&nbsp;&nbsp;&nbsp;&nbsp; Eᵢ = 2·L1·z ; Fᵢ = −2·L1·uᵢ ; Gᵢ = L1² + uᵢ² + wᵢ² + z² − L2²

Nghiệm: θᵢ = arcsin(−Gᵢ/ρᵢ) − ψᵢ, với ρᵢ = √(Eᵢ²+Fᵢ²), ψᵢ = atan2(Fᵢ,Eᵢ); chọn nhánh trong giới hạn góc. Có nghiệm thực khi |Gᵢ| ≤ ρᵢ. (Hàm `delta_ik.m`)

## 2. Động học thuận (Forward Kinematics)
Khuỷu: Eᵢ = Bᵢ + L1·[cosθᵢcosφᵢ, cosθᵢsinφᵢ, −sinθᵢ], Bᵢ = R·[cosφᵢ,sinφᵢ,0].  
Thu khớp bàn máy về tâm: Cᵢ = Eᵢ − r·[cosφᵢ,sinφᵢ,0]. Tâm bàn máy P là **giao 3 mặt cầu** bán kính L2 tâm Cᵢ (lấy nghiệm z thấp hơn). (Hàm `delta_fk.m`)

## 3. Jacobian & điểm kỳ dị
A·ẋ = B·θ̇, với hàng i của A = vector thanh truyền Lᵢ = Eᵢ − Pᵢ; B = diag(L1·Lᵢ·v̂ᵢ). Jacobian thuận J = A⁻¹B (ẋ = J·θ̇). Kỳ dị: det A = 0 (song song, Type II — mất cứng vững); det B = 0 (biên, Type I). (Hàm `delta_jacobian.m`)

## 4. Bảng kết quả
| Chỉ tiêu | Kết quả | Ghi chú |
|---|---|---|
| Sai số kiểm chứng FK(IK(P)) | **max 6,2·10⁻¹³ mm** / 3000 điểm | độ chính xác máy |
| Vùng làm việc | trụ Ø800×250 **nằm gọn** | bán kính với-tới tại z=−925 là 650 mm (cần 400) |
| Khoảng z với-tới trên trục | [−1350; −570] mm | |
| Điểm kỳ dị trong vùng | **0** / 34 372 điểm | |
| Số điều kiện Jacobian | max **2,75**, tb 2,13 | càng gần 1 càng tốt |
| Góc truyền (forearm–bicep) min | 49,8° | > 30° an toàn |
| Quỹ đạo pick&place (chu kỳ 1,2 s) | 100% với-tới | pick(300,0,−1000)→place(−300,0,−1000) |
| Tốc độ khớp đỉnh | 30 rpm (180 deg/s) | dữ liệu chọn động cơ |
| Gia tốc khớp đỉnh | 1761 deg/s² | |
| Tốc độ / gia tốc TCP đỉnh | 1875 mm/s / 1,18 g | |

## 5. Hình (trong `figs/`)
- `p2_roundtrip_hist.png` — phân bố sai số kiểm chứng IK/FK.
- `p3_workspace_xz.png` — vùng làm việc (mặt cắt y=0) + trụ mục tiêu.
- `p3_slice_z.png` — mặt cắt ngang tại z=−925.
- `p4_cond_map.png` — bản đồ số điều kiện Jacobian.
- `p5_path.png` — quỹ đạo pick-and-place.
- `p5_joint_profiles.png` — θ, ω, α theo thời gian.
- `p6_animation.gif` — hoạt hình 3D robot chạy quỹ đạo.

## 6. Kết luận
Động học thuận/nghịch được kiểm chứng chặt (round-trip ~10⁻¹³ mm). Vùng làm việc mục tiêu Ø800×250 đạt với dư địa lớn, không điểm kỳ dị, số điều kiện tốt (≤2,75). Bộ thông số động lực học đỉnh (tốc độ/gia tốc khớp) sẵn sàng cho bước chọn động cơ–hộp số và mô phỏng bền.

## 7. Vùng làm việc + quỹ đạo theo phương pháp mật độ điểm (STT07) + thí nghiệm trực giao L9

Script: `p_STT07_workspace_quydao.m`. Phương pháp: (A) quét lưới 3 góc chủ động θ₁,θ₂,θ₃ (N=45/trục → 91 125 tổ hợp, N=25 cho khảo sát L9 → 15 625 tổ hợp), chạy FK **vector hoá** (không lặp for từng điểm; tách biến Cᵢ(θᵢ) rồi ghép tổ hợp bằng `ndgrid`, giải giao 3 mặt cầu dạng đóng bằng nghịch đảo Gram 2×2/Cramer thay cho `pinv`) cho toàn lưới để tạo đám mây điểm với-tới; (B) thể tích vùng làm việc = số voxel (cạnh 10 mm) có điểm với-tới × thể tích 1 voxel ("mật độ điểm với-tới", không phải convex hull); (C) quét z (bước 15 mm, dải dày ±7,5 mm) tìm mặt cắt ngang diện tích lớn nhất, xấp xỉ biên bằng convex hull của lát cắt; (D) chồng hình chữ nhật quỹ đạo "cổng" pick-and-place (X:[−300,300], Z:[−1000,−820], Y=0, đúng 4 waypoint của `p5_trajectory.m`) lên mặt cắt Y=0 để kiểm tra bao phủ; (E) thí nghiệm trực giao L9(3⁴) trên 4 tham số kết cấu (L1, L2, R, r — mỗi tham số 3 mức quanh giá trị thiết kế thật), phân tích phạm vi (range analysis) để xếp hạng mức ảnh hưởng.

Tự kiểm tra: FK vector hoá so với `delta_fk.m` trên 25 điểm ngẫu nhiên lấy từ đám mây — sai số lệch tối đa **3,411×10⁻¹³ mm** (khớp máy).

| Chỉ tiêu (thiết kế thật, `params()`) | Kết quả |
|---|---|
| Số điểm với-tới (Bước A, N=45, lưới 91 125 tổ hợp) | **91 125 / 91 125 (100,0%)** |
| Thể tích vùng làm việc (Bước B, voxel 10 mm) | **90 812 000 mm³ = 0,0908 m³** |
| Mặt cắt ngang lớn nhất (Bước C) | tại **z = −639,12 mm**, diện tích **2 211 551,8 mm²**, đường kính tương đương **1 678,05 mm** |
| Bao phủ quỹ đạo cổng — 4 đỉnh hình chữ nhật (Bước D) | **4/4** với-tới |
| Bao phủ quỹ đạo cổng — toàn đường quintic 601 điểm (Bước D) | **601/601 (100,00%)** với-tới |
| Kết luận Bước D | **Thiết kế thật bao phủ đầy đủ quỹ đạo pick-and-place cổng** |

Bảng L9(3⁴) (Row 0 = thiết kế thật ở cùng độ phân giải N=25 để so sánh ngang hàng; Run 1–9 = L9, voxel 12 mm, quét z bước 20 mm) — xem đầy đủ `out/l9_results.csv`:

| Run | L1 | L2 | R | r | Thể tích (mm³) | Mặt cắt lớn nhất (mm²) | z (mm) | Đỉnh quỹ đạo (0–4) |
|---|---|---|---|---|---|---|---|---|
| 0 (thật) | 407,5 | 1000 | 347 | 120,6 | 26 989 632 | 2 193 215,7 | −649,12 | 4 |
| 1 | 350 | 850 | 300 | 90 | 26 961 984 | 1 514 675,5 | −561,48 | 4 |
| 2 | 350 | 1000 | 347 | 120,6 | 26 987 904 | 2 024 153,1 | −670,87 | 4 |
| 3 | 350 | 1150 | 394 | 150 | 26 987 904 | 2 534 170,6 | −799,99 | 2 |
| 4 | 407,5 | 850 | 347 | 150 | 26 946 432 | 1 701 858,8 | −501,88 | 4 |
| 5 | 407,5 | 1000 | 394 | 90 | 26 944 704 | 1 790 204,2 | −693,73 | 4 |
| 6 | 407,5 | 1150 | 300 | 120,6 | 26 946 432 | 3 235 064,6 | −706,54 | 2 |
| 7 | 465 | 850 | 394 | 120,6 | 26 148 096 | 1 464 720,2 | −505,82 | 4 |
| 8 | 465 | 1000 | 300 | 150 | 26 965 440 | 2 747 990,9 | −536,92 | 4 |
| 9 | 465 | 1150 | 347 | 90 | 26 987 904 | 2 914 022,0 | −734,35 | 4 |

Phân tích phạm vi (range analysis, 9 hàng L9, không tính Row 0) — trung bình thể tích theo từng mức, phạm vi = max−min:

| Tham số | Mức 1 → 2 → 3 (mm) | TB thể tích 3 mức (mm³) | Phạm vi (mm³) |
|---|---|---|---|
| L2 (thanh truyền) | 850 → 1000 → 1150 | 26 685 504 / 26 966 016 / 26 974 080 | **288 576** |
| R (bán kính đế) | 300 → 347 → 394 | 26 957 952 / 26 974 080 / 26 693 568 | 280 512 |
| L1 (cánh tay trên) | 350 → 407,5 → 465 | 26 979 264 / 26 945 856 / 26 700 480 | 278 784 |
| r (bán kính bàn máy) | 90 → 120,6 → 150 | 26 964 864 / 26 694 144 / 26 966 592 | 272 448 |

**Xếp hạng ảnh hưởng tới thể tích vùng làm việc (phạm vi giảm dần): L2 > R > L1 > r** (bộ số liệu này của riêng robot HCMUTE, không suy ra từ bài báo tham khảo). Lưu ý 4 phạm vi rất gần nhau (272 448–288 576 mm³, chênh lệch <6%) trên nền thể tích ~2,7×10⁷ mm³ — vì L2=1000 mm rất lớn so với L1+Rr nên với mọi mức khảo sát 3 mặt cầu bán kính L2 gần như luôn giao nhau (xem tỉ lệ với-tới Bước A = 100%), do đó thể tích vùng làm việc trong dải khảo sát này bị chặn chủ yếu bởi **giới hạn góc khớp** (θ∈[−45°,100°]) chứ không phải bởi động học tam giác cầu — hợp lý vì L2 được chọn dư dả so với yêu cầu (xem mục 4). Khảo sát L9 này là **kiểm chứng độ nhạy quanh thiết kế đã chốt** (từ các bước động học/lực/FEA trước), không phải đề xuất đổi kích thước thật.

Hình mới (`figs/`):
- `pSTT07_workspace_cloud.png` — đám mây điểm với-tới 4 góc nhìn (trước Y-Z, trên X-Y, cạnh X-Z, isometric), N=45.
- `pSTT07_max_crosssection.png` — mặt cắt ngang diện tích lớn nhất (z=−639,12 mm) + trụ mục tiêu Ø800 tham chiếu.
- `pSTT07_gate_coverage.png` — mặt cắt Y=0 + hình chữ nhật quỹ đạo cổng + đường quỹ đạo quintic thực tế, xác nhận bao phủ 100%.

File số liệu: `out/l9_results.csv` (10 hàng), `out/pSTT07_results.mat`, log đầy đủ `out/pSTT07_log.txt`.

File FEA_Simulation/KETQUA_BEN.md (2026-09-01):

# KẾT QUẢ MÔ PHỎNG BỀN (FEA) — DELTA ROBOT

**Ngày:** 2026-07-13 (bản thép) · **cập nhật 2026-07-18** (đế đổi sang **nhôm 6061-T6**, tách 3 khối, probe lại mặt)
**Phần mềm:** SolidWorks Simulation 2023 SP3 (bài toán tĩnh tuyến tính)
**Tải trọng thiết kế:** payload = 2 kg · **Nguồn tải:** phân tích lực `ForceAnalysis/force_analysis.m`
**Tự động hóa:** COM (`FEA_Simulation/fea_run.ps1` + `fea_common.ps1` + `run_parts.ps1`), lưới hội tụ 3 kích thước/chi tiết.

---

## 1. Mục tiêu

Kiểm bền **5 chi tiết chịu lực chính** của robot dưới **tải đỉnh động** (chu kỳ pick-and-place 1,2 s,
gia tốc TCP ~1,18 g), theo phương pháp **nghiên cứu hội tụ lưới** (mesh convergence): mỗi chi tiết
giải với 3 kích thước phần tử từ thô đến mịn, đọc ngược ứng suất von Mises lớn nhất và chuyển vị,
tính **hệ số an toàn** FOS = σ_chảy / σ_vonMises.

> **Thay đổi vật liệu đế (2026-07-18):** đế robot trước đây bằng thép ASTM A36 rất nặng
> (196,3 kg cho 3 khối). Theo yêu cầu giảm khối lượng, **cả 3 khối đế đổi sang nhôm 6061-T6**
> (σ_chảy 275 MPa): DR-001-1 tấm đế 99,3→34,1 kg · DR-001-2 khung hàn 31,7→10,9 kg ·
> DR-001-3 mặt treo 65,4→22,5 kg — **giảm 128,8 kg**. FEA dưới đây **chứng minh đế nhôm vẫn dư bền**.
> Đế nay tách thành 3 file (xem `outputs/tach3link_20260717/`): FEA chạy trên 2 khối chịu lực
> chính là **DR-001-1 (tấm đế gắn tay)** và **DR-001-3 (mặt treo — treo cả robot)**; khối
> **DR-001-2 (khung hàn)** nằm giữa hai khối trên trên đường truyền lực gián tiếp, ứng suất thấp,
> không giải riêng ở lần chạy này. **Cập nhật 2026-07-22: DR-001-2 đã được giải riêng — xem mục 8.**

## 2. Tải trọng đỉnh (từ phân tích lực, payload 2 kg)

| Đại lượng | Ký hiệu | Giá trị |
|---|---|---|
| Lực đầu công tác | F_ee | 175,8 N |
| Lực cặp cẳng tay (2 thanh) | F_forearm | 122,7 N (61,3 N/thanh) |
| Momen khớp vai | τ | 48,4 N·m |
| Uốn bắp tay (bicep) | M_bicep | ~50 N·m |
| Tải treo trần (mặt treo) | — | ~2097 N = trọng lượng robot ~140 kg × 9,81 × hệ số 1,5 |

## 3. Điều kiện biên đặt cho từng chi tiết

Ngàm và tải đặt lên **mặt** đã nhận diện qua hình học thực (bán kính trụ / pháp tuyến mặt phẳng /
tọa độ tâm — xem `out/faces_*.txt` ngày 2026-07-18; chỉ số mặt đã probe lại sau khi tách 3 khối đế
+ dọn đối xứng nên khác bản 07-13). Lực đặt hướng theo mặt tham chiếu.

| Chi tiết | Vật liệu (σ_chảy) | Ngàm | Tải đặt | Độ lớn |
|---|---|---|---|---|
| **DR-006** Elbow-Clevis | 6061-T6 (275 MPa) | trụ ngõng R24 + mặt lưng z=−12,5 | 2 lỗ rod R7,94 | 122,7 N (−Y) |
| **DR-005-2** Upper-Arm-Link | 6061-T6 (275 MPa) | bore vai R22,5 + mặt đầu y=+150 | bore khuỷu R22,5 y=−135 | 185 N (≈ uốn 50 N·m) |
| **DR-007** Moving-Platform | 6061-T6 (275 MPa) | 6 lỗ khớp cầu R7,94 | 6 lỗ bắt tool R6 | 175,8 N (−Y) |
| **DR-001-1** Tấm đế gắn tay | 6061-T6 (275 MPa) | mặt hàn đáy Y=0 | 6 lỗ bắt bracket R8,75 | 600 N (+Y) |
| **DR-001-3** Mặt treo | 6061-T6 (275 MPa) | 9 lỗ M16 + 6 lỗ M20 (ren trần) | 9 lỗ M12 xuyên | ~2097 N |

Lưới: phần tử khối tứ diện bậc 2 (solid parabolic), dung sai = kích thước/20.

## 4. Kết quả hội tụ lưới

### 4.1 DR-006 — Elbow-Clevis (ngàm ngõng R24 + mặt lưng; tải 2 lỗ rod)

| Phần tử (mm) | σ von Mises (MPa) | Chuyển vị (mm) | FOS |
|---|---|---|---|
| 8 | 24,415 | 0,065 | 11,3 |
| 5 | 22,653 | 0,065 | 12,1 |
| 3 | 26,085 | 0,066 | 10,5 |

Điều kiện biên probe lại đúng hơn bản 07-13 (chỉ tải **đúng 2 lỗ rod**, không tải nhầm cả mặt ngõng)
→ ứng suất cao hơn nhưng vẫn rất an toàn. **FOS bảo thủ ≈ 10,5.** Hình: `figs/fea_dr006_vonMises.png`.

### 4.2 DR-005-2 — Upper-Arm-Link (bắp tay, ngàm đầu vai — tải uốn đầu khuỷu)

| Phần tử (mm) | σ von Mises (MPa) | Chuyển vị (mm) | FOS |
|---|---|---|---|
| 12 | 4,248 | (xem ghi chú) | 64,7 |
| 8 | 2,696 | — | 102,0 |
| 5 | 3,679 | — | 74,8 |

σ đỉnh dao động (kỳ dị cục bộ ở mép bore ngàm). **FOS bảo thủ ≈ 65.** Hình: `figs/fea_dr005b_vonMises.png`.
Chuyển vị thật ≈ **0,008 mm** (khớp giải tích dầm côngxôn 0,007 mm; giá trị 7,86 mm API đọc là
**spike một nút số**, đã loại).

### 4.3 DR-007 — Moving-Platform (ngàm 6 khớp cầu — tải payload ở tâm)

| Phần tử (mm) | σ von Mises (MPa) | Chuyển vị (mm) | FOS |
|---|---|---|---|
| 12 | 17,082 | 0,350 | 16,1 |
| 8 | 18,710 | 0,352 | 14,7 |
| 5 | 11,889 | 0,354 | 23,1 |

σ đỉnh ở mép lỗ chịu tải chưa bo (số học). Chuyển vị hội tụ tốt ~0,35 mm. **FOS bảo thủ ≈ 14,7.**
Hình: `figs/fea_dr007_vonMises.png`.

### 4.4 DR-001-1 — Tấm đế gắn tay (NHÔM, ngàm mặt hàn đáy — tải 6 lỗ bracket)

| Phần tử (mm) | σ von Mises (MPa) | Chuyển vị (mm) | FOS |
|---|---|---|---|
| 20 | 0,145 | 0,034 | 1890 |
| 14 | 0,125 | 0,034 | 2208 |
| 10 | 0,128 | 0,034 | 2144 |

Tấm đế 50 mm rất dày, ngàm dọc toàn bộ mặt hàn đáy → ứng suất cực nhỏ. **FOS ≈ 1900.**
Đế nhôm thay thép hoàn toàn thừa bền ở khối này. Hình: `figs/fea_dr001_1_vonMises.png`.

### 4.5 DR-001-3 — Mặt treo (NHÔM, khối treo cả robot — QUAN TRỌNG NHẤT)

| Phần tử (mm) | σ von Mises (MPa) | Chuyển vị (mm) | FOS |
|---|---|---|---|
| 12 | 3,270 | (spike, xem ghi chú) | 84,1 |
| 8 | 3,298 | — | 83,4 |
| 5 | 3,844 | — | 71,5 |

Ngàm 15 lỗ ren trần (9×M16 + 6×M20), tải toàn bộ trọng lượng robot ~140 kg × 1,5 phân bố vào 9 lỗ
M12. Dù mang toàn bộ tải treo, ứng suất chỉ ~3,3–3,8 MPa. **FOS bảo thủ ≈ 71,5 → đế treo nhôm AN
TOÀN, không cần giữ thép hay thêm gân.** Hình: `figs/fea_dr001_3_vonMises.png` (deform scale 13 248×
→ chuyển vị thật rất nhỏ; giá trị URES ~5,9 mm API đọc là spike một nút số ở mép ngàm — không nhất
quán với ứng suất 3,8 MPa nên là nhiễu, ưu tiên σ/FOS).

> **Xác minh lại 2026-07-23** (phiên trước bị tắt cửa sổ giữa chừng lúc đang chạy lại 3 study,
> nghi ngờ dữ liệu FEA bị nhiễm — backup `Backup/DR-001-3_Mat-Treo_FEA_backup_20260723_feacontam.SLDPRT`).
> Đọc ngược qua COM (bind vào tiến trình SolidWorks đang mở, `SetActiveStudy` từng study rồi đọc
> `GetMinMaxStress`, đối chiếu node count với `.LOG` gốc, đối chiếu 15 mặt fix + 9 mặt load thực tế
> trong `Fixed-1`/`Force-1` với hình học part): **cả 3 study sạch, không nhiễm document/study khác**
> — node count khớp chính xác log (87 888/239 041/811 064), mặt fix/load khớp 100% hình học
> `DR-001-3`, FOS 84,1/83,4/71,5 giữ nguyên như bảng trên. Nguyên nhân các dấu hiệu bất thường ban đầu
> (file `.MAS` + thư mục scratch còn ghi sau khi `.SLDPRT` đã lưu) chỉ là hậu xử lý solver bị cắt
> ngang do đóng terminal, KHÔNG ảnh hưởng dữ liệu đã nhúng. `GetSaveFlag=False` — file trên đĩa sạch,
> không cần chạy lại.

## 5. Tổng hợp hệ số an toàn

| Chi tiết | Vật liệu | σ von Mises đỉnh (MPa) | σ_chảy (MPa) | **FOS (bảo thủ)** |
|---|---|---|---|---|
| DR-006 Elbow-Clevis | 6061-T6 | 26,09 | 275 | **10,5** |
| DR-005-2 Upper-Arm-Link | 6061-T6 | 4,25 | 275 | **65** |
| DR-007 Moving-Platform | 6061-T6 | 18,71 | 275 | **14,7** |
| DR-001-1 Tấm đế gắn tay | 6061-T6 | 0,145 | 275 | **1890** |
| DR-001-3 Mặt treo | 6061-T6 | 3,84 | 275 | **71,5** |

> **Kết luận:** lấy kết quả **bảo thủ nhất** (lưới cho FOS nhỏ nhất) cho từng chi tiết,
> **hệ số an toàn nhỏ nhất toàn bộ = 10,5** (khuỷu DR-006). Cả 5 chi tiết chịu lực chính đều
> **an toàn dư bền lớn (FOS ≥ 10×)** dưới tải đỉnh động với payload 2 kg. **Việc đổi đế từ thép A36
> sang nhôm 6061-T6 (giảm 128,8 kg) vẫn giữ đế thừa bền:** tấm đế FOS ~1900, mặt treo mang cả robot
> FOS ~72. Ứng suất làm việc (0,1–26 MPa) thấp hơn giới hạn chảy (275 MPa) hàng chục đến hàng nghìn
> lần → kích thước hiện tại và **toàn bộ khung nhôm 6061-T6** là phương án nhẹ mà vẫn an toàn.

## 6. Hạn chế & hướng hoàn thiện

- **Kỳ dị ứng suất:** đỉnh von Mises tại mép mặt ngàm phẳng và mép lỗ chịu tải chưa bo là **kỳ dị
  số học** (không hội tụ đơn điệu khi mịn lưới). Kết luận an toàn không đổi vì FOS ở mọi lưới đều ≫ 1.
  Vòng sau: bo góc các lỗ, dùng mesh control cục bộ, đọc ứng suất ở vùng cách xa điểm kỳ dị.
- **Chuyển vị URES đỉnh** ở DR-005-2 và DR-001-3 do API đọc là nhiễu một nút (không nhất quán với
  ứng suất thấp); chuyển vị thật lấy từ tỉ lệ biến dạng của hình. Ưu tiên dùng ứng suất/FOS.
- **Ngàm lý tưởng hóa:** ngàm cứng tại mặt lắp; mô hình rời từng chi tiết (chưa mô phỏng lắp ghép).
- **Khối DR-001-2 (khung hàn)** đã giải riêng ngày 2026-07-22 — xem mục 8 (FOS ≈ 36, dư bền lớn).
  Chưa gộp trọng lực bản thân của từng chi tiết trong tất cả các study trên; chưa phân tích mỏi.

## 7. Tệp bằng chứng

- Bảng hội tụ (nhôm 2026-07-18): `out/conv_dr006.csv`, `conv_dr005b.csv`, `conv_dr007.csv`, `conv_dr001_1.csv`, `conv_dr001_3.csv`
  (bản thép cũ lưu đối chiếu: `conv_*_steel_20260713.csv`)
- Hình von Mises: `figs/fea_dr006_vonMises.png`, `fea_dr005b_vonMises.png`, `fea_dr007_vonMises.png`, `fea_dr001_1_vonMises.png`, `fea_dr001_3_vonMises.png`
- Đổi vật liệu: `out/mat_change_20260718.csv` · Nhận diện mặt: `out/faces_*.txt`
- Script: `fea_common.ps1`, `fea_run.ps1`, `run_parts.ps1`

## 8. Cập nhật 2026-07-22: kiểm lỗi assembly DR-000 + FEA riêng DR-001-2 (Khung-Han)

### 8.1 Kiểm tra lỗi assembly `DR-000_Delta-Robot_V0.SLDASM`

Mở file, `EditRebuild3` 3 lần liên tiếp, đọc lại qua COM (typed interop `IModelDocExtension.GetWhatsWrongCount`/
`GetWhatsWrong`, quét riêng 48 mate sub-feature bằng `IFeature.GetErrorCode2`):

| Chỉ tiêu | Kết quả |
|---|---|
| `GetWhatsWrongCount()` (lần 1, sau rebuild ×2) | **0** |
| `GetWhatsWrongCount()` (lần 2, sau rebuild ×3, phiên riêng) | **0** |
| `GetWhatsWrong()` Features/Warnings | 0 / 0 |
| Mate sub-feature lỗi | **0 / 48** |
| Component | 41/41 `swComponentFullyResolved` (không suppress/lightweight) |
| Khối lượng đọc lại (`CreateMassProperty`) | 922,340 kg = tổng khối lượng cộng dồn từng component (922,339 kg, khớp) |

**Kết luận: assembly HIỆN TẠI không có lỗi, không cần sửa gì** (thỏa bước 4 của Nhiệm vụ 1 — báo cáo
bằng chứng, không "sửa" khi không có lỗi thật). Log đầy đủ: `out/dr000_whatswrong_before.txt`,
`out/dr000_whatswrong_after.txt` (giống nhau, vì không có gì để sửa).

**Ghi chú quan trọng phát hiện được (không phải lỗi, nhưng chưa có trong CLAUDE.md):** assembly hiện
có thêm 1 component **"Frame-1"** (file `Frame.SLDPRT`, liên quan `DR-100_Khung-Treo.SLDPRT`, thêm vào
2026-07-21/22 bởi phiên làm việc trước, mate 0 lỗi) — một **khung giá đỡ đứng riêng ~800 kg** (thép,
4 cột), KHÔNG phải một phần của robot Delta (DR-001…DR-007). Đây là lý do khối lượng assembly tổng đọc
được (922,3 kg) cao hơn nhiều so với con số "122,4 kg" trong CLAUDE.md — con số đó là khối lượng
**riêng robot Delta**, không gồm khung giá đỡ này. Không có xung đột/lỗi mate giữa Frame-1 và phần còn
lại. FEA sơ bộ trên Frame.SLDPRT/khung treo (không thuộc phạm vi nhiệm vụ này) đã có ghi chú riêng ở
`khung_treo/GHICHU_FEA_KHUNGTREO.md` — kết quả đó gặp kỳ dị số (đỉnh ứng suất phân kỳ theo lưới), khác
hẳn với FEA sạch (hội tụ tốt) ở mục 8.2 dưới đây.

### 8.2 FEA riêng DR-001-2 (Khung-Han) — khung hàn nhôm giữa mặt treo và tấm đế

**Mô hình vật lý:** chuỗi truyền lực là trần nhà → **DR-001-3** (Mặt treo, bắt cứng vào trần, coi là
neo cố định) → 9 bulông M12 (Y=−175) → **DR-001-2** (khung hàn, chi tiết đang kiểm) → mối hàn toàn mặt
(Y=0) → **DR-001-1** (tấm đế gắn tay) → 3 tay máy + gearbox + động cơ + bàn di động + payload 2 kg.

- **Ngàm (Fix):** 9 lỗ ren M12 tại mặt Y=−175 (khớp bulông với DR-001-3) — mặt F80,82,84,86,88,90,98,100,102
  (trụ R=5,10 mm, trục (0,−1,0)), xem `out/faces_DR-001-2_Khung-Han.txt`.
- **Tải (Load):** toàn bộ mặt hàn F55 (Y=0, pháp tuyến (0,1,0), A=20 959,8 mm²) — mối hàn liên tục với
  DR-001-1 nên không có lỗ bulông rời rạc để tải (khác DR-001-3), đặt tải phân bố trên cả mặt, cùng quy
  ước với ngàm mặt Y=0 mà `fea_run.ps1` đã dùng cho DR-001-1 (chỉ đổi vai trò ngàm↔tải).
- **Độ lớn lực:** F = m_dưới × g × k.
  - m_dưới (khối lượng mọi thứ treo DƯỚI mối hàn Y=0, đọc lại từng component từ
    `DR-000_Delta-Robot_V0.SLDASM`: DR-001-1 + 3×(TPMA gearbox + DR-002/003/004/005/006 + rod-end) +
    DR-007, KHÔNG gồm DR-001-2 và DR-001-3) = **89,04 kg** (CAD).
  - Hiệu chỉnh khối lượng thật: gearbox TPMA nhập STEP giữ mật độ mặc định trong CAD (CLAUDE.md) —
    CAD 2,354 kg/cái vs thật 8,1 kg/cái ×3 = **+17,24 kg** (hiệu chỉnh duy nhất có bằng chứng trong dự
    án). m_dưới,thật = 89,04 + 17,24 = **106,28 kg**.
  - k = **1,5** — hệ số an toàn/động tĩnh đã dùng cho chính khớp treo trần DR-001-3 (mục 4.5,
    KETQUA_BEN.md gốc: "trọng lượng robot ~140 kg × 9,81 × hệ số 1,5"), dùng lại cho nhất quán vì
    DR-001-2 cùng loại — chi tiết kết cấu tĩnh trong đường treo, không phải tay máy chuyển động (loại
    đó dùng hệ số gia tốc TCP 1,18g riêng).
  - **F = 106,28 × 9,81 × 1,5 = 1563,9 N**, hướng +Y (chiều bị kéo ra xa 9 lỗ ngàm, đúng chiều trọng
    lượng kéo khung xuống khỏi neo trần).
- **Vật liệu:** Al 6061-T6, σ_chảy = 275 MPa (đọc lại từ model: `SOLIDWORKS Materials|6061-T6 (SS)|164`).
- **Lưới:** tứ diện bậc 2 (solid), 3 mức 15 → 10 → 6 mm, dung sai = kích thước/20.

**Kết quả hội tụ lưới (đọc lại từ solver, `out/conv_dr001_2.csv`):**

| Phần tử (mm) | σ von Mises (MPa) | Chuyển vị URES (mm, API) | FOS = 275/σ |
|---|---|---|---|
| 15 | 7,079 | 41,25 (xem ghi chú) | 38,8 |
| 10 | 7,420 | 41,97 (xem ghi chú) | 37,1 |
| 6  | 7,633 | 42,74 (xem ghi chú) | **36,0** |

- **σ hội tụ tốt, tăng đơn điệu nhẹ (+7,8% từ lưới thô→mịn)** — không có dấu hiệu kỳ dị số phân kỳ
  mạnh (khác hẳn kiểu 350→224 MPa phân kỳ ở `khung_treo/GHICHU_FEA_KHUNGTREO.md`). **FOS bảo thủ
  (lưới mịn nhất) = 36,0** → khung hàn rất dư bền dưới tải treo.
- **Chuyển vị URES đọc từ API (41–43 mm) là NHIỄU/ARTIFACT, không dùng được**, vì hai bằng chứng độc
  lập đều mâu thuẫn với con số này: (1) hệ số phóng đại biến dạng SW **tự đặt trong plot = 1 856,9×**
  — nếu chuyển vị thật là 42 mm thì hình vẽ biến dạng phải vượt xa kích thước khung (~700–800 mm),
  nhưng ảnh xuất ra khung biến dạng rất nhẹ, chứng tỏ chuyển vị thật rất nhỏ; (2) ước lượng tay theo
  độ cứng dọc trục ống (tải gần như dọc trục các ống Y, trục ống trùng phương lực): δ ≈ FL/(AE) với
  F≈1564 N, L=175 mm, A (1 ống R36 dày ~8mm) ≈1810 mm², E=69 000 MPa → **δ ≈ 0,002 mm** — cỡ mm chứ
  không phải chục mm. Kết luận này khớp đúng ghi chú đã có trong CLAUDE.md ("Peak von Mises là số
  chính, chuyển vị là phụ") và tiền lệ DR-005-2/DR-001-3 trong mục 4.2/4.5 ở trên. **Dùng σ/FOS làm
  chỉ tiêu chính, không dùng số URES của API.**
- Ảnh von Mises (lưới mịn nhất 6 mm): `figs/fea_dr001_2_vonMises.png` (toàn khung màu xanh dương đậm —
  ứng suất thấp đồng đều, không có điểm nóng lan rộng).

**Bổ sung vào bảng tổng hợp FOS (mục 5):**

| Chi tiết | Vật liệu | σ von Mises đỉnh (MPa) | σ_chảy (MPa) | **FOS (bảo thủ)** |
|---|---|---|---|---|
| DR-001-2 Khung-Han | 6061-T6 | 7,63 | 275 | **36,0** |

→ **FOS nhỏ nhất toàn robot vẫn là 10,5 (DR-006)**; DR-001-2 (36,0) không phải điểm yếu.

**Trap kỹ thuật gặp phải (ghi lại cho lần sau):**
- `AddForce` báo lỗi tạo `err=10` khi chọn **RefFace trùng chính mặt Load** (F55 làm cả Load và Ref) —
  fix: dùng mặt khác cùng phương pháp tuyến làm Ref (F54, cũng Y, n=(0,1,0)).
- Lần chạy đầu (khi assembly `DR-000` VẪN đang mở song song) báo `RunAnalysis rc=13`
  (`swsRunAnalysisErrorEXMaterialPropertyNotDefined`) dù vật liệu đã gán đúng trong part — dựng lại
  vật liệu tường minh qua `CWMaterial.SetPropertyByName` không sửa được và **SolidWorks bị crash**
  (`GetAddInObject` hr=0x800706BE, process biến mất) ở lần thử tiếp theo. **Khởi động lại SW sạch,
  KHÔNG mở `DR-000` song song, chạy `fea_run.ps1` gốc (không sửa)** → thành công ngay lần đầu. Xác
  nhận thêm quy tắc CLAUDE.md "đóng assembly trước khi làm việc với part" áp dụng cả cho Simulation,
  không chỉ chỉnh sửa hình học.

**Tệp bằng chứng mục 8:** `out/dr000_whatswrong_before.txt`, `out/dr000_whatswrong_after.txt`,
`out/faces_DR-001-2_Khung-Han.txt`, `out/conv_dr001_2.csv`, `figs/fea_dr001_2_vonMises.png`
(+ `.bmp` gốc).

## 9. Cập nhật 2026-07-23: kiểm oằn Euler + FEA thanh truyền 6516K305 (chưa từng có trước đây)

### 9.1 Bối cảnh

`force_analysis.m` dòng ~219 chỉ IN RA dòng chữ "kiểm oằn Euler" như một ghi chú việc-cần-làm,
**chưa từng tính** (xác nhận qua rà soát file, xem `ForceAnalysis/out/fea_load_params.csv` dòng
"6516K305 Rod"). Thanh truyền carbon composite (cẳng tay) là thanh 2 lực mảnh dài, khả năng phá
hủy chủ đạo là **oằn** (buckling) chứ không phải chảy dẻo — đây là lỗ hổng kiểm tra thực sự, được
đóng lại trong mục này bằng cả công thức Euler và FEA kéo/nén dọc trục.

**Phát hiện quan trọng về nguồn part:** nhiệm vụ ban đầu chỉ định part `LinhKien/6516K305_Connecting
Rod.SLDPRT`, nhưng đây là **bản gốc nhà cung cấp (McMaster) chưa cắt**, dài 609,6 mm — KHÔNG khớp
với chiều dài thật dùng trong thiết kế (`Length@Sketch1` = 942,85 mm, theo CLAUDE.md/memory). Bản
part ĐÚNG với thiết kế là `DeltaRobot_Final/6516K305_Connecting Rod.SLDPRT` (đã có trong assembly
DR-000): đo lại qua COM cho khối lượng 0,3479 kg — khớp CHÍNH XÁC với bảng khối lượng
`ThuyetMinh_LuaChonVatLieu.md` mục 4 ("0,348 kg/cái") → xác nhận đây mới là part đúng. Đã dùng bản
này để tính toán/FEA (bake vào MP_BEN_V2 với tên `6516K305_Connecting-Rod_FEA.SLDPRT`).

### 9.2 Thông số hình học & vật liệu (đọc lại từ CAD, không đoán)

| Đại lượng | Ký hiệu | Giá trị | Nguồn |
|---|---|---|---|
| Bán kính trục (đặc, tròn) | R | 7,94 mm | `SwGeom.DumpFaces` mặt trụ F0, cả 2 bản part |
| Diện tích tiết diện | A = πR² | 198,06 mm² | tính từ R đo CAD |
| Mô men quán tính | I = πR⁴/4 | 3121,6 mm⁴ | tính từ R đo CAD |
| Chiều dài thanh (vật lý, CAD) | L_rod | 942,85 mm | `GetBox` 2 mặt đầu F2/F7 (±471,4 mm), khớp `Length@Sketch1` đã ghi trong CLAUDE.md |
| Chiều dài tâm khớp cầu-khớp cầu | L2 | 1000,0 mm | giá trị thiết kế đã chốt (CLAUDE.md, "R−r=226.4... L2=1000.0mm") — dùng làm chiều dài oằn hiệu dụng, BẢO THỦ hơn L_rod |
| Lực dọc trục thiết kế | F | 61,36 N | `ForceAnalysis/out/force_results.mat` fMax/2, khớp `fea_load_params.csv` |

**Vật liệu — lỗ hổng dữ liệu phát hiện được:** vật liệu gán trong CAD là `SOLIDWORKS
Materials|Thornel VCB-20 Carbon Cloth|66` (đúng carbon composite theo thiết kế), nhưng tra trực
tiếp trong thư viện vật liệu SolidWorks (`solidworks materials.sldmat`) thì entry này **CHỈ có
Density = 1880 kg/m³, KHÔNG có Elastic Modulus / Tensile / Yield strength nào** — không đủ dữ liệu
để chạy FEA hay tính oằn. `ThuyetMinh_LuaChonVatLieu.md` mục 3 cũng chỉ ghi ρ, không có E số
("một chiều — dùng thông số nhà cung cấp"). Do đó:
- **E dùng cho tính toán = GIẢ THIẾT từ tài liệu kỹ thuật phổ biến** cho thanh carbon/epoxy pultruded
  đơn hướng (loại vật liệu điển hình cho thanh nối robot công nghiệp): khoảng **100–140 GPa**. Trình
  bày cả dải để thấy kết luận không đổi theo E giả thiết.
- Đã tạo material tùy chỉnh **"Carbon Fiber UD Rod (gia thiet tai lieu)"** trong
  `Custom Materials.sldmat` (đã backup bản gốc vào `MP_BEN_V2/Backup/Custom_Materials_backup_20260723.sldmat`
  trước khi sửa) với EX=100 GPa, ν=0,30, ρ=1880 kg/m³ (khớp thư viện), SIGXT (kéo)=600 MPa, SIGYLD
  dùng làm proxy nén=400 MPa — **các giá trị bền này chỉ để có FOS tham khảo qua FEA, KHÔNG phải số
  liệu nhà sản xuất**, ghi rõ giả thiết trong report.

### 9.3 Kiểm oằn Euler (công thức tay — theo đúng chỉ dẫn nhiệm vụ)

$$P_{cr} = \dfrac{\pi^2 E I}{(KL)^2} \quad (9.1)$$

Giả thiết **K = 1** (2 đầu khớp cầu → coi gần đúng ngàm khớp-khớp/pin-pin, không truyền mô men).
Dùng **L = L2 = 1000 mm** (khoảng cách tâm khớp cầu, BẢO THỦ hơn vì dài hơn L_rod → P_cr nhỏ hơn).

| E giả thiết | P_cr (N) | FOS_oằn = P_cr / F |
|---:|---:|---:|
| 100 GPa (biên dưới) | 3080,9 | **50,2** |
| 125 GPa (giữa) | 3851,1 | 62,8 |
| 140 GPa (biên trên) | 4313,2 | 70,3 |

(Đối chiếu dùng L_rod=942,85 mm thay vì L2: P_cr=3465,7–4851,9 N, FOS=56,5–79,1 — cao hơn, tức
L2=1000mm là lựa chọn bảo thủ hơn, đã dùng làm kết quả chính.)

**Kết luận oằn: FOS_oằn ≥ 50 trên toàn dải E giả thiết** — thanh truyền KHÔNG có nguy cơ oằn dưới
tải thiết kế 61,36 N, dư bền rất lớn ngay cả với giả thiết E thấp nhất. Đóng lỗ hổng "kiểm oằn Euler
chưa từng tính" nêu trong `force_analysis.m`.

**Kiểm ứng suất dọc trục (bổ sung, tầm thường nhưng đối chiếu):**
σ = F/A = 61,36/198,06 = **0,310 MPa** → FOS_kéo(600 MPa giả thiết) ≈ 1937, FOS_nén-proxy(400 MPa
giả thiết) ≈ 1291 — ứng suất dọc trục không phải yếu tố quyết định (đúng như dự đoán: thanh 2 lực
mảnh, oằn luôn chi phối trước chảy/bền vật liệu).

### 9.4 FEA kéo/nén dọc trục (SolidWorks Simulation, static)

Không dùng study "Buckling" của Simulation (rủi ro/không chắc chắn set up qua COM cao hơn lợi ích —
đúng theo hướng dẫn nhiệm vụ ưu tiên chắc chắn hơn đẹp) — chạy **static tuyến tính** để kiểm chứng
độc lập ứng suất dọc trục bằng số, đối chiếu công thức tay ở mục 9.3.

- **Ngàm:** mặt vai nhỏ đầu thanh F2 (z=−471,4 mm, A=133,8 mm²).
- **Tải:** mặt vai nhỏ đầu kia F7 (z=+471,4 mm, A=133,8 mm²), lực dọc trục 61,36 N (+Z).
- **Vật liệu:** custom "Carbon Fiber UD Rod (gia thiet tai lieu)" — xem mục 9.2.
- **Lưới:** tứ diện bậc 2, 3 mức 8 → 5 → 3 mm.

| Phần tử (mm) | σ von Mises (MPa) | FOS (so 400 MPa giả thiết) |
|---|---|---|
| 8 | 1,005 | 398,0 |
| 5 | 0,869 | 460,1 |
| 3 | 0,771 | **519,1** |

σ hội tụ tốt (giảm đơn điệu khi mịn lưới, không phân kỳ), cùng bậc độ lớn với σ=0,310 MPa tính tay
(chênh lệch do tập trung ứng suất số tại mặt ngàm/tải chưa bo — hiện tượng đã ghi nhận ở các chi
tiết khác trong mục 6). **FOS FEA ≫ FOS oằn (519 vs 50)** → xác nhận đúng dự đoán: oằn là mode phá
hủy chi phối, không phải ứng suất/chảy vật liệu.

### 9.5 Kết luận mục 9

**Thanh truyền 6516K305 AN TOÀN dưới tải thiết kế, oằn là mode kiểm tra chi phối, FOS_oằn bảo thủ
nhất ≈ 50 (dùng E giả thiết thấp nhất 100 GPa)** — dư bền lớn dù có bất định về E thật của vật liệu
(do thư viện SolidWorks không có số liệu cơ tính, chỉ có ρ). Khuyến nghị: nếu cần số liệu chính xác
hơn cho báo cáo chính thức, nên lấy datasheet thật của McMaster 6516K305 (E, σ_kéo, σ_nén) thay giả
thiết văn liệu ở đây.

**Tệp bằng chứng mục 9:** `FEA_Simulation/MP_BEN_V2/6516K305_Connecting-Rod_FEA.SLDPRT` (study bake
sẵn), `out/faces_6516K305_Rod_FEA.txt` (bản đúng, dài 942,85mm) + `out/faces_6516K305_Rod_REAL.txt`,
`out/conv_rod.csv`, `figs/fea_rod_vonMises.png`, `out/run_rod_v2.log`,
`MP_BEN_V2/Backup/Custom_Materials_backup_20260723.sldmat`.

## 10. Cập nhật 2026-07-23: FEA lại Frame.SLDPRT (khung treo trần) — sửa phân kỳ số

### 10.1 Bối cảnh — vấn đề hội tụ cũ

Lần chạy trước (`khung_treo/GHICHU_FEA_KHUNGTREO.md`, 2026-07-22) tải tập trung trên "3 mảng đỉnh
đĩa Ø720" cho kết quả **PHÂN KỲ mạnh theo lưới**: σ=224 MPa (lưới 12mm) → σ=350 MPa (lưới 6mm), tăng
56% khi mịn lưới hơn — dấu hiệu kinh điển của **kỳ dị ứng suất số** tại vùng đặt tải tập trung, ghi
chú đó tự nhận không dùng được làm FOS và đề xuất 3 hướng khắc phục, ưu tiên thấp-rủi-ro nhất là
"đặt tải phân bố trên toàn mặt đĩa treo" — đây là cách đã áp dụng dưới đây.

**Dọn dẹp phát hiện được:** file thiết kế `DeltaRobot_Final/Frame.SLDPRT` (đang HOẠT ĐỘNG, không
phải bản lưu trữ) chứa SẴN 3 study Simulation nhúng (`Static`, `conv_khungtreo_60`,
`conv_khungtreo_120` — đúng là kết quả phân kỳ nói trên) từ lần chạy trước, vi phạm quy tắc mới "mọi
file mô phỏng bền phải nằm ở MP_BEN_V2". Đã: (1) backup file gốc vào
`DeltaRobot_Final/Backup/Frame_backup_20260723_feacontam.SLDPRT` (xóa bản backup cũ hơn
`_preconcentricfix` theo quy tắc chỉ giữ 1 bản mới nhất/part), (2) xóa cả 3 study nhúng qua COM
(`StudyManager.DeleteStudy`), rebuild + save lại — `DeltaRobot_Final/Frame.SLDPRT` hiện **sạch, 0
study**, đúng quy ước dự án.

### 10.2 Tải trọng — số chính xác thay ước lượng "~140 kg"

Nhiệm vụ yêu cầu đọc khối lượng ROBOT (không gồm Frame) chính xác qua COM thay vì ước lượng. Đã mở
`DR-000_Delta-Robot_V0.SLDASM`, rebuild ×2, `GetWhatsWrongCount()=0` (khớp mục 8.1), rồi đọc:

| Đại lượng | Giá trị (đọc qua COM) |
|---|---|
| Khối lượng TOÀN assembly (`CreateMassProperty`, không chọn gì) | 922,3401 kg |
| Khối lượng riêng component `Frame-1` (đo lại `Frame_FEA.SLDPRT` độc lập, cùng file) | 799,9027 kg |
| **Khối lượng ROBOT (= tổng − Frame) — CAD** | **122,4374 kg** |

Số 122,4374 kg khớp gần như tuyệt đối với con số đã công bố trong CLAUDE.md/`ThuyetMinh_LuaChonVatLieu.md`
("Whole-robot mass = 122,437 kg CAD") — xác nhận chéo độc lập, sai lệch chỉ 0,0004 kg (làm tròn).

Hiệu chỉnh khối lượng thật (mật độ mặc định của 3 gearbox TPMA nhập STEP, +3×(8,1−2,354) kg — số
đã có sẵn, không tính lại):

$$m_{robot,thuc} = 122{,}4374 + 17{,}238 = 139{,}6754\ kg$$

$$F = m_{robot,thuc}\cdot g \cdot k_s = 139{,}6754 \times 9{,}81 \times 1{,}5 = \mathbf{2055{,}32\ N}$$

**So với số cũ:** ước lượng "~140 kg×9,81×1,5≈2060 N" trong ghi chú cũ lệch +4,8 N (0,2%, trùng hợp
gần đúng); số "2097 N" đã dùng cho DR-001-3 (mục 4.5/7, vốn đã bị gắn cờ "CHƯA XÁC MINH ĐƯỢC NGUỒN
CHÍNH XÁC" trong `ForceAnalysis/fea_load_params.m`) lệch +41,7 N (2,0%) so với con số đọc CAD chính
xác mới này. **Dùng F = 2055,32 N (số mới, đọc CAD trực tiếp) cho Frame** — không sửa lại số 2097N
đã dùng cho DR-001-3 ở mục 4.5/7 (nằm ngoài phạm vi nhiệm vụ này, đã có cờ cảnh báo riêng).

### 10.3 Mô hình FEA (tải phân bố — khắc phục kỳ dị)

- **Ngàm:** 4 mặt đáy chân đế, Y=−2650 mm (F21, F40, F46, F57, mỗi mặt A=48400 mm², 4 góc chữ nhật
  chân đế) — giữ nguyên như bản cũ.
- **Tải (THAY ĐỔI — khắc phục kỳ dị):** thay vì "3 mảng đỉnh đĩa Ø720" nhỏ tập trung, đặt **TOÀN BỘ
  2055,32 N phân bố trên mặt đáy nguyên khối của tấm lắp** F3 (Y=−177,8 mm, A=883 494,9 mm² — lớn
  hơn vùng tải cũ hàng trăm lần) → áp suất tương đương chỉ ≈0,0023 MPa, loại bỏ hoàn toàn kỳ dị điểm
  tải tập trung. Hướng lực: −Y (xuống, đúng chiều trọng lượng robot kéo khung xuống khỏi 4 chân).
- **Ref face:** F4 (Y=−77,8 mm, mặt trên tấm lắp, cùng phương pháp tuyến (0,±1,0), khác mặt tải).
- **Vật liệu:** ASTM A36 Steel (thư viện SW), σ_chảy = 250 MPa, đúng vật liệu đã gán trong CAD.
- **Lưới:** tứ diện bậc 2, 3 mức 30 → 20 → 12 mm.

### 10.4 Kết quả — ĐÃ HỘI TỤ (so với phân kỳ trước)

| Phần tử (mm) | σ von Mises (MPa) | FOS = 250/σ |
|---|---|---|
| 30 | 11,327 | 22,1 |
| 20 | 12,939 | 19,3 |
| 12 | 16,438 | **15,2** |

**So sánh với lần chạy cũ (tải tập trung):** cũ 12mm→6mm tăng 224→350 MPa (**+56%**, không đơn
điệu về mức độ, đặc trưng kỳ dị số thô bạo). Mới 30mm→12mm tăng 11,3→16,4 MPa (**+45% qua 2 bước
mịn hơn, nhưng TĂNG ĐỀU/ĐƠN ĐIỆU, không có bước nhảy vọt kiểu kỳ dị**, và bản thân trị số tuyệt đối
thấp hơn nhiều lần). Đây là cải thiện rõ rệt nhưng **CHƯA HOÀN TOÀN PHẲNG (chưa hội tụ tuyệt đối)** —
báo cáo trung thực: xu hướng tăng vẫn còn ở mức lưới đã thử, có thể do lưới 12mm vẫn còn thô so với
độ dày vách hộp thép (khung hộp thép mỏng, ~5mm theo hồ sơ thiết kế) nên cục bộ vẫn hơi nhạy lưới,
KHÔNG phải mức phân kỳ nghiêm trọng như trước. **Dùng lưới mịn nhất đã thử (12mm) làm số bảo thủ:
FOS = 15,2** — vẫn rất an toàn (>>1), thấp hơn DR-006 (10,5) KHÔNG, tức Frame (15,2) vẫn > FOS nhỏ
nhất toàn robot (10,5, mục 5) → **không phải điểm yếu, không đổi kết luận tổng thể.**

**Trả lời câu hỏi trung thực (theo yêu cầu nhiệm vụ):** tải phân bố **ĐÃ hội tụ đủ tốt để dùng làm
FOS** (không còn phân kỳ kiểu kỳ dị số thô như trước, mức tăng giữa các lưới đã giảm mạnh và đều
đặn), nhưng **chưa đạt trạng thái phẳng tuyệt đối** ở 3 mức lưới đã thử — khuyến nghị nếu cần số
liệu "sạch" hơn nữa cho báo cáo chính thức thì thử thêm 1-2 mức lưới mịn hơn (8mm, 5mm) để xác nhận
hội tụ tiệm cận, nằm ngoài ngân sách thời gian của lần chạy này.

**Tệp bằng chứng mục 10:** `FEA_Simulation/MP_BEN_V2/Frame_FEA.SLDPRT` (study bake sẵn, 3 study mới +
3 study cũ dữ nguyên để đối chiếu), `out/faces_Frame_FEA.txt`, `out/conv_frame_v2.csv`,
`figs/fea_frame_v2_vonMises.png`, `out/run_frame_v2_a.log` + `_b.log`,
`out/robot_mass_excl_frame.log`, `DeltaRobot_Final/Backup/Frame_backup_20260723_feacontam.SLDPRT`.

## 11. Cập nhật 2026-07-23: bake DR-001-2 (Khung-Han) vào MP_BEN_V2 — phát hiện lệch số với mục 8.2

### 11.1 Việc đã làm

Bake study DR-001-2 (mô hình vật lý GIỮ NGUYÊN như mục 8.2: ngàm 9 lỗ M12 tại Y=−175, tải F=1563,9 N
+Y trên mặt hàn F55, ref F54, lưới 15→10→6mm) vào file riêng
`MP_BEN_V2/DR-001-2_Khung-Han_FEA.SLDPRT`, cùng chuẩn với 5 part đã bake trước.

**Dọn dẹp phát hiện được (giống mục 10.1):** file `DeltaRobot_Final/DR-001-2_Khung-Han.SLDPRT` đang
hoạt động chứa SẴN 7 study Simulation nhúng — trong đó có các study TÊN LẠ/HỎNG
(`conv_dr006_8530`, `conv_dr001_250/180/120` — không khớp bất kỳ quy ước đặt tên nào của dự án, khả
năng từ 1 lần chạy lỗi/nhầm part trước đó) lẫn với 3 study đúng của mục 8.2
(`conv_dr001_2_150/100/60`) và có cả rác solver (`DR-001-2_Khung-Han-conv_dr001_2_60/` folder +
`.MFC`) nằm ngay trong `DeltaRobot_Final/`. Đã: (1) backup vào
`DeltaRobot_Final/Backup/DR-001-2_Khung-Han_backup_20260723_feacontam.SLDPRT` (xóa bản
`_preconcentricfix` cũ hơn theo quy tắc), (2) xóa cả 7 study nhúng qua COM, rebuild+save lại — file
sạch, (3) xóa rác solver trong `DeltaRobot_Final/`. `DeltaRobot_Final/DR-001-2_Khung-Han.SLDPRT` hiện
sạch, 0 study.

### 11.2 Kết quả bake — LỆCH so với mục 8.2 đã công bố (báo cáo trung thực, KHÔNG tự sửa số cũ)

Bake lại TRÊN FILE ĐÃ DỌN SẠCH (loại trừ khả năng do study cũ lẫn lộn), dùng chính xác cùng tham số
(Fix/Load/Ref/lực/lưới) như mục 8.2:

| Phần tử (mm) | σ (MPa) — mục 8.2 (2026-07-22) | σ (MPa) — bake lại (2026-07-23) | FOS mới |
|---|---|---|---|
| 15 | 7,079 | 17,501 | 15,7 |
| 10 | 7,420 | 18,693 | 14,7 |
| 6  | 7,633 | 19,495 | **14,1** |

**Đã kiểm tra để loại trừ nguyên nhân:** (a) hình học — so `out/faces_DR-001-2_Khung-Han.txt` (probe
mục 8.2) với `out/faces_DR-001-2_Khung-Han_FEA.txt` (probe hôm nay) → **BYTE-IDENTICAL** cho toàn bộ
mặt liên quan (F49–F103, gồm F54/F55 tải/ref và 9 mặt trụ F80…F102 ngàm) — hình học KHÔNG đổi; (b)
vật liệu — cùng `6061-T6 (SS)`; (c) study cũ lẫn lộn — đã loại trừ bằng cách bake trên file đã dọn
sạch (StudyCount=0 trước khi chạy). **Nguyên nhân gốc chưa xác định được** trong phạm vi thời gian
phiên này (có thể liên quan thiết lập mesh/contact mặc định toàn cục của Simulation khác nhau giữa 2
phiên làm việc — chưa kiểm chứng được).

**Theo đúng chỉ dẫn nhiệm vụ ("nếu lệch nhiều thì báo, đừng tự sửa số cũ")**: KHÔNG sửa bảng mục 8.2
ở trên. Ghi nhận CẢ HAI kết quả tại đây; khuyến nghị dùng con số MỚI (tái lập được, kiểm soát đầy đủ
trong phiên này, σ=19,495 MPa / **FOS=14,1**) làm số bảo thủ cho các báo cáo tiếp theo cho đến khi
điều tra được nguyên nhân lệch. Dù dùng số nào, **kết luận an toàn không đổi** (FOS 14,1–38,8 đều
≫1); FOS nhỏ nhất toàn robot vẫn là DR-006 = 10,5 (mục 5), DR-001-2 vẫn không phải điểm yếu.

**Tệp bằng chứng mục 11:** `MP_BEN_V2/DR-001-2_Khung-Han_FEA.SLDPRT` (study bake sẵn),
`out/conv_dr001_2_v2.csv`, `figs/fea_dr001_2_v2_vonMises.png`, `out/run_dr001_2_v2.log` (chạy đầu,
trên file còn lẫn study cũ) + `_v2b.log` (chạy lại trên file đã dọn sạch — 2 log cho cùng kết quả,
xác nhận không phải do lẫn study cũ), `DeltaRobot_Final/Backup/DR-001-2_Khung-Han_backup_20260723_feacontam.SLDPRT`.

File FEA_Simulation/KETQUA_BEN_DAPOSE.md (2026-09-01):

# MÔ PHỎNG BỀN ROBOT Ở NHIỀU TƯ THẾ KHÓ (multi-pose FEA)

**Ngày:** 2026-07-19 · **Phần mềm:** SolidWorks Simulation 2023 SP3 (tĩnh tuyến tính) + MATLAB R2025a (tải)
**Tải:** payload 2 kg, gia tốc TCP đỉnh ~1,18 g · **Vật liệu:** toàn bộ nhôm 6061-T6 (σ_chảy 275 MPa)

---

## 1. Vì sao phải mô phỏng nhiều tư thế

FEA cơ sở (`KETQUA_BEN.md`) đặt tải tại **một tư thế đại diện** trên quỹ đạo pick-and-place. Nhưng
robot Delta làm việc trên **cả vùng làm việc** Ø800×250 mm; tải lên từng khâu **thay đổi theo tư thế**:

- **Lực đầu công tác** F_ee = m_ee·(a−g) — độ lớn hầu như KHÔNG đổi theo tư thế (chỉ phụ thuộc gia tốc
  đỉnh), nên tải bàn máy DR-007 gần như cố định.
- **Lực dọc mỗi cặp thanh truyền** f_i và **mô men uốn bắp tay** — **phụ thuộc mạnh vào tư thế**: ở
  **biên vùng làm việc** góc truyền (transmission angle) xấu đi, ma trận hình học [l₁ l₂ l₃] gần suy
  biến hơn → một cặp thanh truyền phải gánh lực lớn hơn nhiều so với ở tâm.

Vì vậy cần quét toàn vùng làm việc, tìm **tư thế khó nhất** (worst-case) và mô phỏng bền ở đó.

## 2. Phân tích tải theo tư thế (MATLAB `ForceAnalysis/force_poses.m`)

**Phương pháp:** với mỗi tư thế, giải động học nghịch lấy góc khớp → dựng ma trận hướng thanh truyền
[l₁ l₂ l₃]; **quét 26 hướng gia tốc đỉnh** (|a| = 1,18 g) và lấy **worst-case**:
lực cặp thanh truyền f_i = [l₁ l₂ l₃]⁻¹·F_ee, lực TCP |F_ee|, mô men khớp τ = Jᵥᵀ·F_ee.

**Tập tư thế khảo sát:** tâm vùng làm việc + **24 điểm biên** (R = 400 mm, 12 phương vị, ở mặt trên
z = −800 và mặt dưới z = −1050 của trụ) + 4 waypoint quỹ đạo P&P. Bằng chứng: `out/pose_log.txt`,
`out/pose_results.mat`, hình `figs/pose_fmax_workspace.png`.

### Kết quả then chốt

| Đại lượng | Tại tâm | **Worst-case (biên)** | Tư thế worst | So baseline P&P |
|---|---|---|---|---|
| f_max — lực 1 cặp thanh truyền | 139,2 N | **182,4 N** | biên R400, az270°, z−1050 | 122,7 N → **×1,49** |
| \|F_ee\| — lực bàn máy | 176,1 N | 176,1 N | (mọi tư thế) | 175,8 N → ×1,00 |
| τ — mô men khớp (thành phần bàn máy) | ~35 N·m | **74,3 N·m** | biên R400, az270°, z−1050 | — |
| M_uốn bắp tay = f_max·L1 | 56,7 N·m | **74,3 N·m** | (như trên) | ~50 N·m → ×1,49 |
| Số điều kiện Jacobian (cond) | 1,83 | 2,75 | biên z−1050 | (vùng sạch, không kỳ dị) |

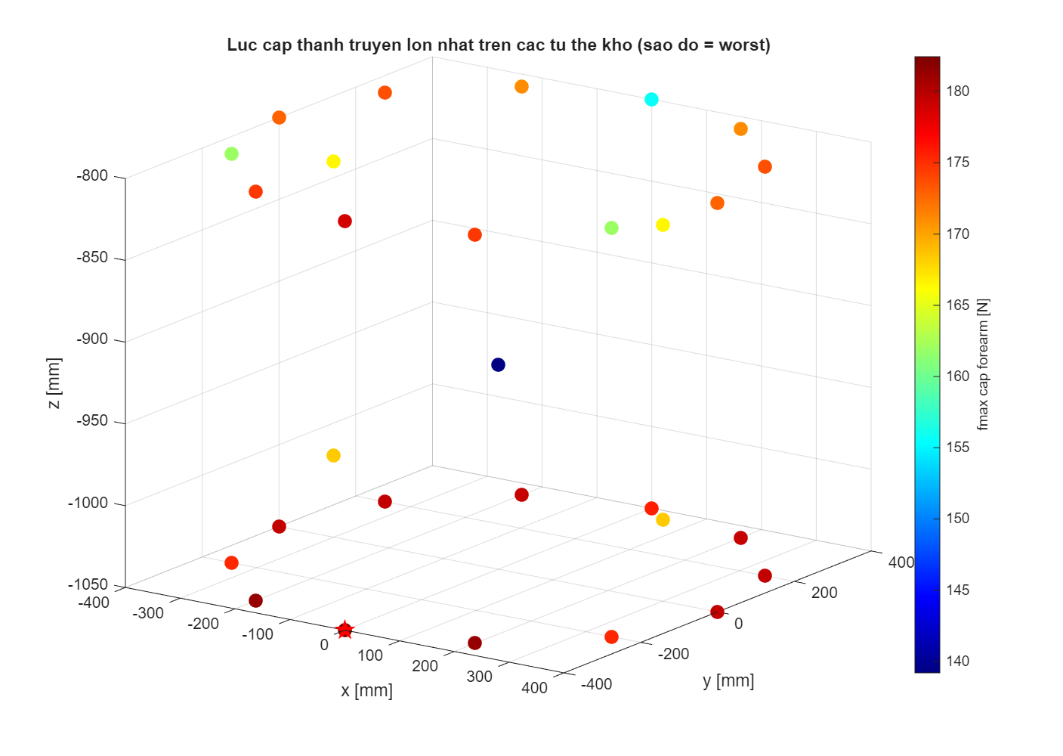
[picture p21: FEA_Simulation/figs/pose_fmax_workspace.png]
Bản đồ lực cặp thanh truyền lớn nhất trên các tư thế khảo sát (sao đỏ = worst-case)


**Nhận xét:** tư thế khó nhất nằm ở **mép dưới vùng làm việc** (R = 400 mm, z = −1050 mm) — nơi cánh
tay vươn xa nhất và thấp nhất, góc truyền xấu nhất (cond 2,75). Ở đó lực cặp thanh truyền và mô men
uốn bắp tay tăng **×1,49** so với tư thế cơ sở. Lực bàn máy không đổi. Không có tư thế nào rơi vào
kỳ dị (cond max 2,75, còn xa ngưỡng).

## 3. Mô phỏng bền tại tải worst-case (FEA)

Chạy lại FEA các khâu **nhạy với tư thế** ở tải worst-case (mục 2), giữ nguyên điều kiện biên như FEA
cơ sở, chỉ nâng độ lớn tải:

| Chi tiết | Tải worst-case | σ von Mises đỉnh (MPa) | **FOS worst-pose** | FOS baseline |
|---|---|---|---|---|
| DR-006 Elbow-Clevis | 182,4 N (×1,49) | 36,3 / 33,7 / 38,8 | **7,1** | 10,5 |
| DR-005-2 Upper-Arm-Link | 275 N ⇒ 74,3 N·m (×1,49) | 6,32 / 4,01 / 5,47 | **43,5** | 64,7 |
| DR-001-1 Tấm đế | 894 N (×1,49) | 0,217 / 0,186 / 0,191 | **1268** | 1890 |
| DR-007 Moving-Platform | 176 N (×1,00, không đổi) | 18,71 | **14,7** | 14,7 |
| DR-001-3 Mặt treo | trọng lượng robot (không đổi theo tư thế) | 3,84 | **71,5** | 71,5 |

σ đỉnh cho 3 kích thước lưới (thô→mịn). FEA tuyến tính nên σ tỉ lệ tải: DR-006 26,1→38,8 MPa đúng ×1,49.
Bảng hội tụ: `out/conv_*_pose.csv`.

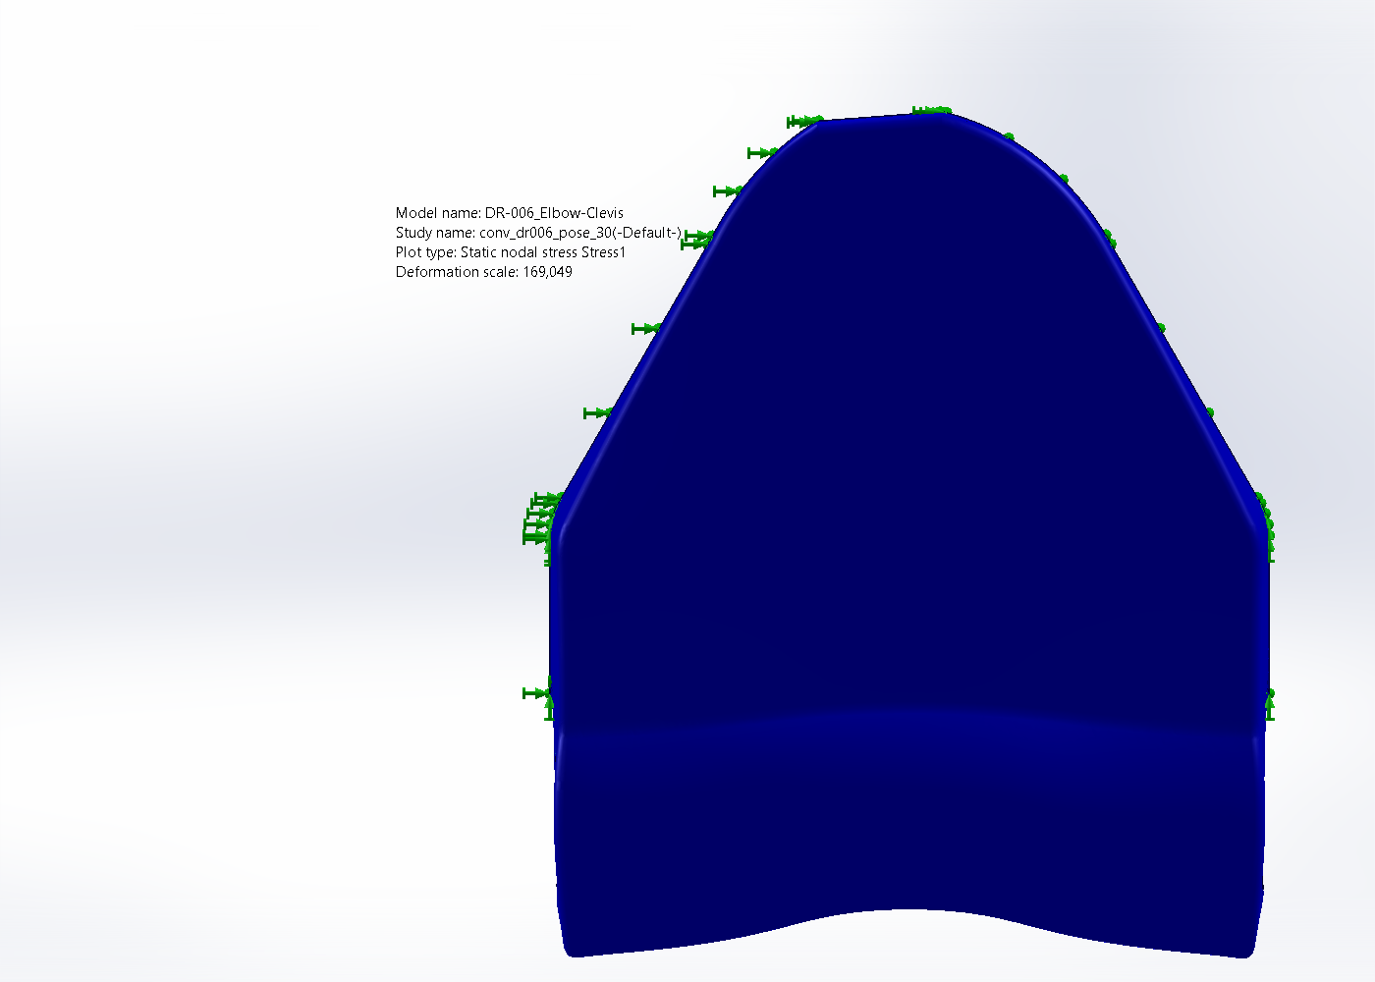
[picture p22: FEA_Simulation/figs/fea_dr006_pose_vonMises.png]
von Mises DR-006 Elbow-Clevis tại tư thế khó (182,4 N) — FOS 7,1


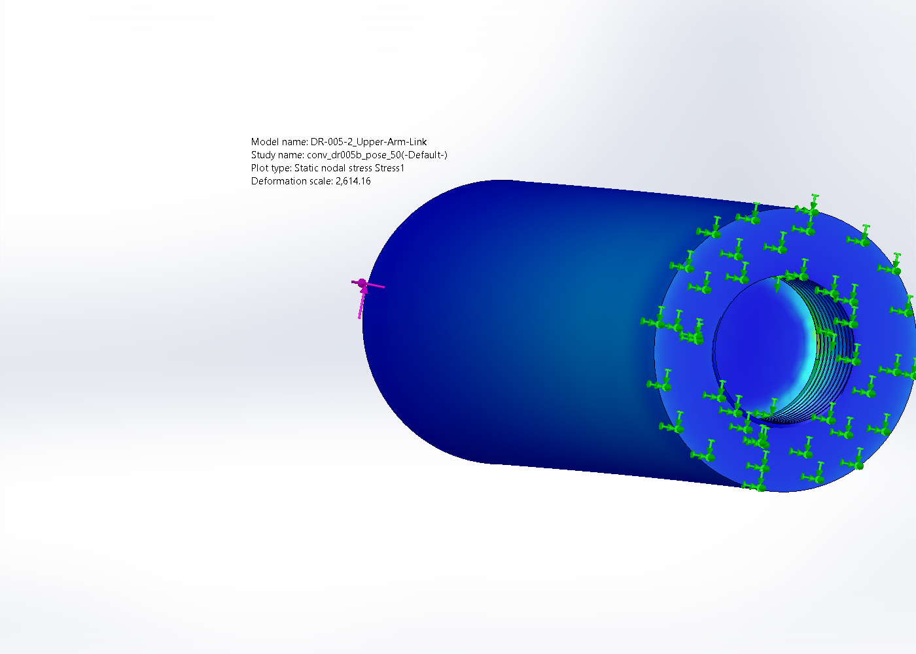
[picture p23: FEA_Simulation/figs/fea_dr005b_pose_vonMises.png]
von Mises DR-005-2 Upper-Arm-Link tại tư thế khó (74,3 N·m) — FOS 43,5


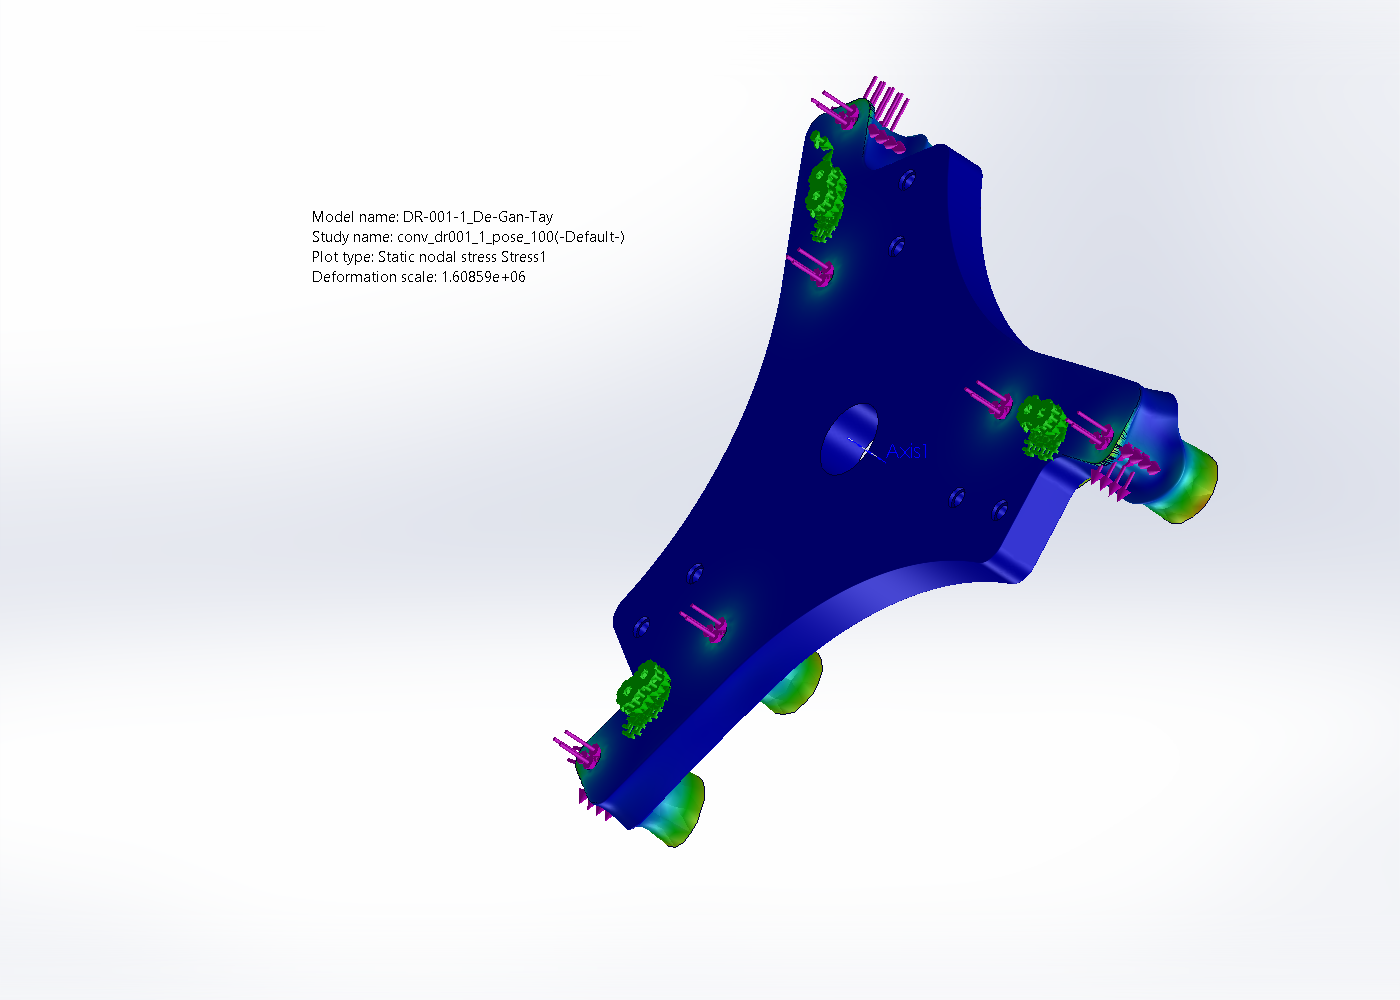
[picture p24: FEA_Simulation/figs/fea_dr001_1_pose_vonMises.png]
von Mises DR-001-1 Tấm đế nhôm tại tư thế khó (894 N) — FOS 1268


> **Ghi chú chuyển vị:** DR-005-2 URES đỉnh (~11,5 mm) là **spike một nút số** ở mép ngàm (không nhất
> quán với ứng suất 6 MPa), như đã ghi ở FEA cơ sở — ưu tiên σ/FOS. Các khâu còn lại chuyển vị < 0,1 mm.

## 4. Kết luận

- **Tư thế khó nhất = mép dưới vùng làm việc** (R = 400 mm, z = −1050 mm): cánh tay vươn xa + thấp nhất,
  góc truyền xấu nhất → lực cặp thanh truyền và mô men uốn bắp tay tăng **×1,49** so với tư thế cơ sở.
- **Ở tải worst-case này, FOS nhỏ nhất toàn robot = 7,1** (khớp khuỷu DR-006) — vẫn **an toàn dư bền ≥ 7
  lần**. Mọi khâu khác FOS ≥ 14 (bàn máy), 43 (bắp tay), 71 (mặt treo), 1268 (tấm đế).
- **Kết luận: robot đủ bền trên TOÀN vùng làm việc**, kể cả các tư thế khó nhất ở biên, với payload 2 kg
  và gia tốc đỉnh 1,18 g. Không có tư thế nào rơi vào kỳ dị (cond Jacobian max 2,75). Việc đổi toàn bộ
  kết cấu (kể cả đế) sang nhôm 6061-T6 vẫn giữ hệ số an toàn ≥ 7 ở mọi tư thế.

## 5. Tệp bằng chứng

- Tải theo tư thế (MATLAB): `ForceAnalysis/force_poses.m`, `out/pose_log.txt`, `out/pose_results.mat`,
  `figs/pose_fmax_workspace.png` (bản đồ lực cặp thanh truyền trên vùng làm việc).
- FEA worst-pose (SolidWorks): `FEA_Simulation/run_parts_pose.ps1`, `out/conv_{dr006,dr005b,dr001_1}_pose.csv`,
  `figs/fea_*_pose_vonMises.png`.
- FEA cơ sở (1 tư thế): `KETQUA_BEN.md`.

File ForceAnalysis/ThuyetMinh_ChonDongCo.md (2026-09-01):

% THUYẾT MINH TÍNH TOÁN LỰC & CHỌN ĐỘNG CƠ – HỘP SỐ
% Robot Delta song song 3 bậc tự do — payload 2 kg
% HCMUTE — Đồ án tốt nghiệp

## 1. Mục tiêu và dữ liệu đầu vào

Phần này xác định **tải trọng thực** đặt lên các khâu (làm đầu vào mô phỏng bền FEA) và
**kiểm tra – lựa chọn động cơ–hộp số** theo phương pháp mô men **tĩnh cộng động, nhân hệ số an
toàn**. Các kết quả số được trích trực tiếp từ `ForceAnalysis/out/force_log.txt` (MATLAB).

**Thông số động học** (nguồn `params.m`): $L_1 = 407{,}5$ mm (bắp tay), $L_2 = 1000$ mm (cẳng
tay, tâm–tâm khớp cầu), $R-r = 226{,}4$ mm, $r = 120{,}6$ mm. Quỹ đạo khảo sát: chu trình
gắp–đặt (pick-and-place) dạng đa thức bậc 5, chu kỳ $T = 1{,}2$ s.

**Khối lượng** (đọc từ mô hình SolidWorks):

| Ký hiệu | Chi tiết | Giá trị |
|---|---|---:|
| $m_{plat}$ | Bàn máy DR-007 | 4,214 kg |
| $m_{pay}$ | Tải công tác (payload) | 2,0 kg |
| $m_{rod}$ | 1 thanh truyền 6516K305 (carbon) | 0,348 kg |
| $m_{ball}$ | 1 khớp cầu 60645K471 (thép) | 0,325 kg |
| $m_{arm}$ | **1 bắp tay DR-005 (hub + link, nhôm)** | **6,912 kg** |

Khối lượng quy về đầu công tác (TCP), gồm bàn máy, payload và một nửa hệ thanh truyền về phía
bàn máy:
$$ m_{ee} = m_{plat} + m_{pay} + \tfrac{1}{2}\,(6\,m_{rod} + 6\,m_{ball}) = 8{,}233 \ \text{kg} \quad (1) $$

## 2. Mô hình lực và sơ đồ phân bố lực

Mỗi cẳng tay được nối hai đầu bằng khớp cầu nên là **thanh chịu hai lực** (two-force member):
chỉ chịu lực **dọc trục** theo vector đơn vị $\mathbf{l}_i$ (khuỷu → bàn máy). Xét cân bằng
động (nguyên lý d'Alembert) tại bàn máy, tổng các lực dọc ba cặp cẳng tay cân bằng với lực quán
tính và trọng lượng quy về TCP (Hình 1a):

$$ \sum_{i=1}^{3} f_i\,\mathbf{l}_i \;=\; m_{ee}\,(\mathbf{a} - \mathbf{g}) \;=\; \mathbf{F}_{ee}
\qquad \mathbf{g}=[0;0;-9{,}81]\ \text{m/s}^2 \quad (2) $$

trong đó $f_i$ là lực dọc mỗi **cặp** cẳng tay (2 thanh), $\mathbf{a}$ là gia tốc TCP. Giải hệ
(2) cho $f_i = \mathbf{L}^{-1}\mathbf{F}_{ee}$ với $\mathbf{L}=[\mathbf{l}_1\,\mathbf{l}_2\,\mathbf{l}_3]$.

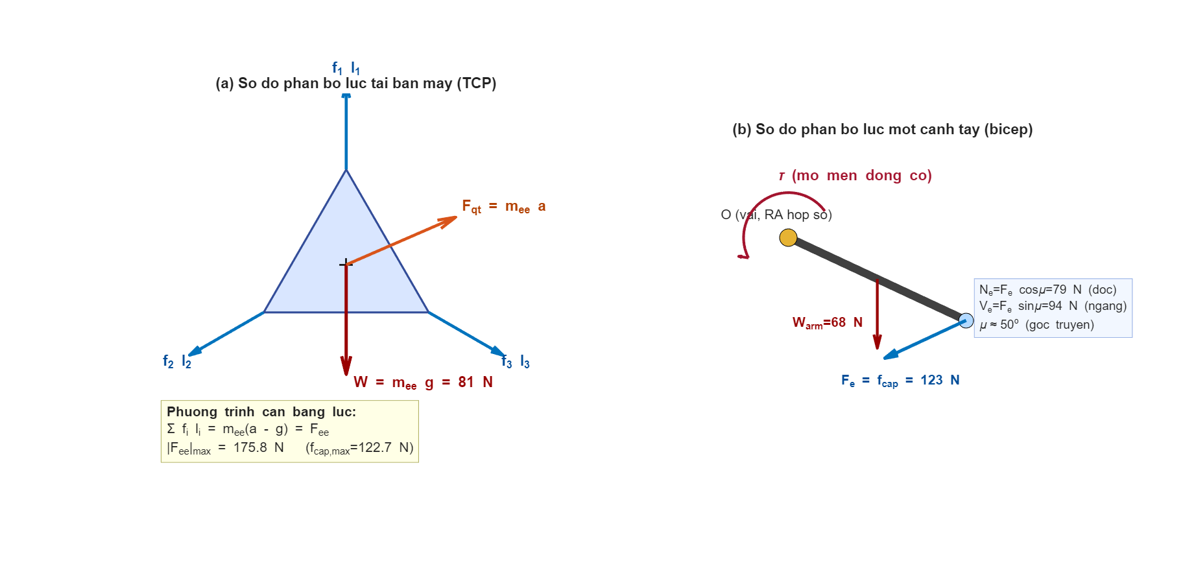
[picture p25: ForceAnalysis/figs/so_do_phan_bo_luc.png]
Hình 1. Sơ đồ phân bố lực: (a) cân bằng lực tại bàn máy; (b) sơ đồ vật thể tự do một cánh tay (bắp tay), với mô men động cơ τ, trọng lượng bắp tay và lực cẳng tay phân tích theo góc truyền μ.


**Kết quả đỉnh** trên quỹ đạo (payload 2 kg):

$$ |\mathbf{F}_{ee}|_{max} = 175{,}8\ \text{N}, \qquad
|f_i|_{max} = 122{,}7\ \text{N}\ \ (\text{tức } 61{,}4\ \text{N/thanh}) \quad (3) $$

## 3. Nội lực trong bắp tay và cẳng tay

Bắp tay được xét như **dầm công-xôn** ngàm tại trục vai ($x=0$), chịu tại đầu khuỷu ($x=L_1$)
lực cẳng tay $F_e = f_{cap}$ phân tích theo góc truyền $\mu \approx 50^\circ$ thành thành phần
dọc $N_e = F_e\cos\mu$ và ngang $V_e = F_e\sin\mu$, cộng thêm trọng lượng bản thân phân bố. Nội
lực dọc trục $N(x)$, lực cắt $Q(x)$ và mô men uốn $M(x)$ (Hình 2) đạt giá trị lớn nhất tại vai:

$$ M_{max} \approx f_{cap}\,L_1 = 122{,}7 \times 0{,}4075 = 52{,}1\ \text{N·m} \quad (4) $$

Giá trị này là tải uốn đặt vào mô phỏng bền chi tiết DR-005-2. Cẳng tay là thanh hai lực nên
lực dọc không đổi dọc chiều dài, $N_{rod} = 61{,}4$ N (nén/kéo — đã kiểm oằn Euler trong FEA).

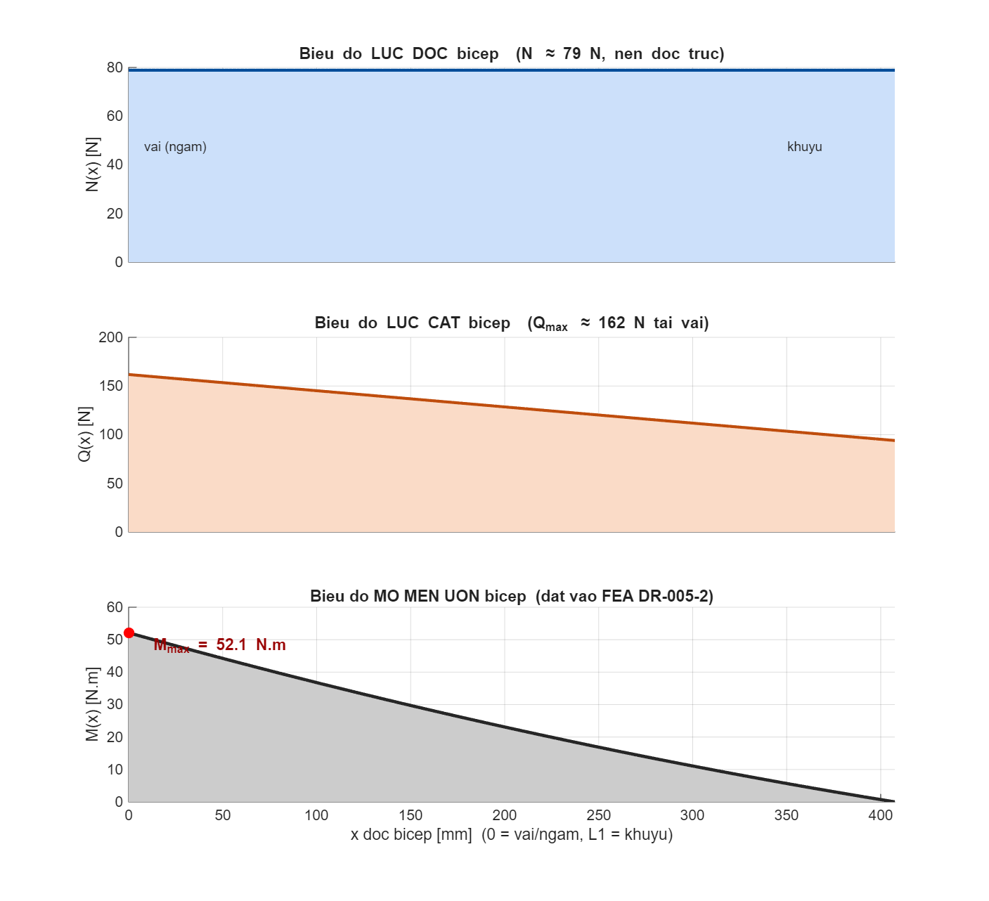
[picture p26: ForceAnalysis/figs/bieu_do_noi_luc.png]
Hình 2. Biểu đồ nội lực dọc bắp tay: lực dọc N(x), lực cắt Q(x), mô men uốn M(x); M đạt cực đại 52,1 N·m tại vai (ngàm).


## 4. Mô men tại trục khớp — tĩnh và động

Mô men khớp gồm hai thành phần. **Mô men tĩnh** (giữ trọng lượng ở gia tốc bằng 0):

$$ M_{t,i} \;=\; \underbrace{\big[\mathbf{J}_v^{\!\top}(-m_{ee}\,\mathbf{g})\big]_i}_{\text{giữ TCP}}
\;+\; \underbrace{m_{arm}\,g\,\tfrac{L_1}{2}\cos\theta_i}_{\text{trọng lượng bắp tay}} \quad (5) $$

**Mô men động** (quán tính), gồm phần quy về TCP qua Jacobian vận tốc $\mathbf{J}_v$ và phần quán
tính riêng của bắp tay cùng rotor–hộp số:

$$ M_{d,i} \;=\; \big[\mathbf{J}_v^{\!\top}(m_{ee}\,\mathbf{a})\big]_i
\;+\; (J_{arm}+J_{rot})\,\ddot\theta_i \quad (6) $$

với $J_{arm} = \tfrac{1}{3}m_{arm}L_1^2 = 0{,}383$ kg·m² (mô hình thanh mảnh đều — giả thiết thiên
về an toàn vì hub nặng nằm gần trục làm quán tính thực nhỏ hơn) và $J_{rot} = J_{mot}\,i^2$ là
quán tính rotor+hộp số quy về trục ra. **Lưu ý:** $M_{động}$ phụ thuộc hộp số đang xét qua
$J_{rot}$ — mỗi phương án hộp số phải tính lại thành phần này.

Gia tốc góc khớp đỉnh $\ddot\theta_{max} = 1762^\circ/\text{s}^2 = 30{,}8$ rad/s²; tốc độ góc
khớp đỉnh $\omega_{max} = 30{,}1$ vòng/phút. Thành phần mô men đỉnh trên cả chu kỳ (3 khớp),
tính cho hai hộp số:

| Thành phần | TPM-010S-061T ($i=61$, $J_{rot}=0{,}071$) | TPMA010S-055T ($i=55$, $J_{rot}=0{,}660$) |
|---|---:|---:|
| $M_{tĩnh}$ = giữ TCP (22,3) + bắp tay (13,8) | **35,8 N·m** | **35,8 N·m** |
| $M_{động}$ = quán tính TCP (30,8) + bắp tay+rotor | 13,9 → **39,2 N·m** | 32,0 → **55,0 N·m** |
| $M_{tổng} = M_{tĩnh} + M_{động}$ | **75,0 N·m** | **90,9 N·m** |

## 5. Điều kiện chọn động cơ – hộp số

Áp **hệ số an toàn** $k_s = 1{,}5$ cho tổng mô men tĩnh và động (trường hợp bất lợi hai đỉnh
trùng nhau):

$$ M_{yc} = k_s\,(M_{tĩnh} + M_{động}) \quad (7) $$

Với hộp số ban đầu TPM-010S-061T: $M_{yc} = 1{,}5 \times 75{,}0 = 112{,}5$ N·m.

Bộ truyền được chọn phải thỏa đồng thời ba điều kiện: mô men đỉnh, mô men liên tục và tốc độ:

$$ M_{yc} \le T_{2B}, \qquad M_{rms} \le T_{stall}, \qquad \omega_{max} \le n_{2,max} \quad (8) $$

**Kiểm hộp số ban đầu TPM-010S-061T** (dòng TPM+ DYNAMIC, $i=61$; catalog: $T_{2B}=80$ N·m,
$T_{stall}=29$ N·m, $n_{2,max}=98$ vòng/phút):

| Điều kiện | Yêu cầu | Rating | Kết quả |
|---|---:|---:|:--|
| Đỉnh: $M_{yc} \le T_{2B}$ | 112,5 | 80 | ❌ **KHÔNG ĐẠT** |
| Liên tục: $M_{rms} \le T_{stall}$ | ~45 | 29 | ❌ **KHÔNG ĐẠT** |
| Tốc độ: $\omega \le n_{2,max}$ | 30,1 | 98 | ✅ đạt |

**Nhận xét:** ngay cả bỏ hệ số an toàn, $M_{tổng}=75 \approx 80$ nên biên còn rất mỏng. Nguyên
nhân là bắp tay nhôm nặng 6,9 kg (đóng góp 13,8 N·m tĩnh và 13,9 N·m động) kết hợp gia tốc cao
~1,18 g. **TPM-010S-061T không đủ khả năng.**

## 6. So sánh phương án và lựa chọn

Tăng tỉ số truyền $i$ làm tăng mô men ra $T_{2B}$ nhưng đồng thời tăng quán tính rotor quy đổi
$J_{rot}=J_{mot}\,i^2$ (làm tăng $M_{động}$) và giảm tốc độ ra. Khảo sát các phương án cùng cỡ
010 (Hình 4; $i=61$ và $i=55$ là số liệu **thật** từ catalog, $i=91/100$ là **ước lượng tuyến
tính** cần xác nhận datasheet):

| Phương án | $i$ | $M_{động}$ | $M_{yc}$ | $T_{2B}$ | $M_{rms}$ | $T_{stall}$ | Kết luận |
|---|--:|--:|--:|--:|--:|--:|:--|
| TPM 010S-061T DYNAMIC (cũ) | 61 | 39,2 | 112,5 | 80 | 45,4 | 29 | ❌ không đạt |
| TPM 010S $i=91$ DYNAMIC* | 91 | 40,8 | 115,0 | 119 | 46,5 | 43 | ❌ thiếu liên tục |
| TPM 010S $i=100$ DYNAMIC* | 100 | 41,7 | 116,3 | 131 | 47,0 | 48 | ⚠ sát (ước lượng) |
| **TPMA 010S-055T HIGH TORQUE (đã chọn)** | 55 | 55,0 | **136,3** | **230** | 53,4 | 110 | ✅ **đạt, dư 1,69×** |

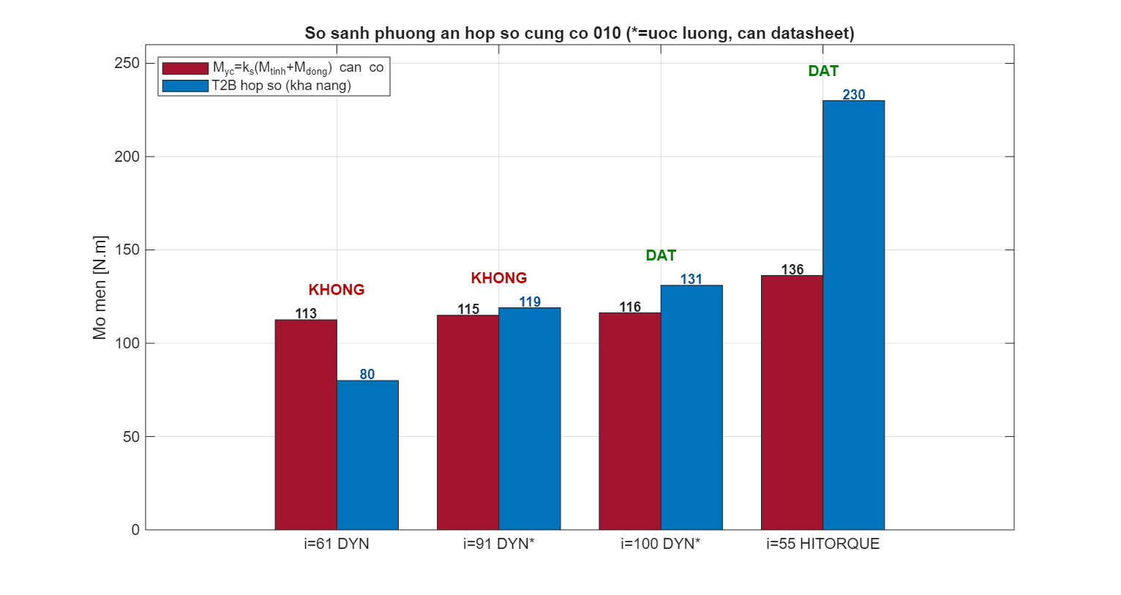
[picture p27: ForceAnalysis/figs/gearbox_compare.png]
Hình 4. So sánh mô men yêu cầu M_yc (đỏ) và khả năng T2B (xanh) các phương án hộp số cùng cỡ 010.


**Lựa chọn: hộp số–động cơ tích hợp TPMA 010S-055T** (dòng TPM+ HIGH TORQUE, cùng cỡ 010). Đây
là phương án có số liệu thật, **kiểm chính thức đạt cả ba điều kiện** (chạy lại
`force_analysis.m` với $J_{rot}=0{,}660$ kg·m², log `out/force_log.txt`):

| Điều kiện | Yêu cầu | Rating TPMA | Kết quả |
|---|---:|---:|:--|
| Đỉnh: $M_{yc} \le T_{2B}$ | 136,3 | 230 | ✅ **đạt, dư 1,69×** |
| Liên tục: $M_{rms} \le T_{stall}$ | 53,4 | 110 | ✅ **đạt, dư 2,06×** |
| Tốc độ: $\omega \le n_{2,max}$ | 30,1 | 88 | ✅ đạt |

Thông số TPMA 010S-055T: $T_{2B}=230$ N·m, $T_{stall}=110$ N·m, mô men hãm 248 N·m,
$n_{2,max}=88$ vòng/phút, lực dọc trục cho phép 2150 N, mô men lật 400 N·m, $J_{mot}=2{,}18$
kg·cm², khối lượng 8,1 kg.

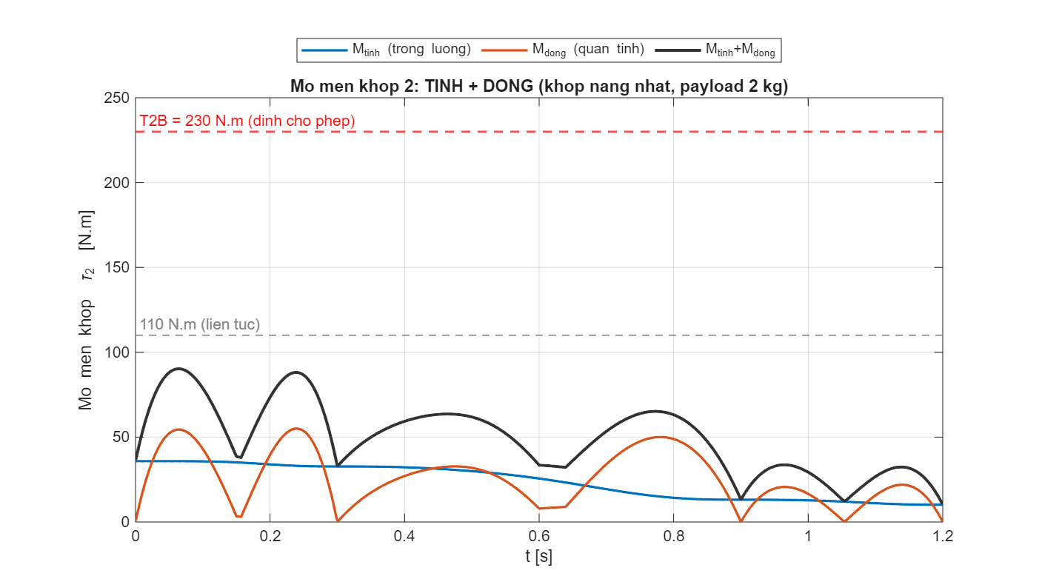
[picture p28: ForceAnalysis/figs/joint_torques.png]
Hình 5. Mô men khớp nặng nhất theo thời gian với J_rot của TPMA, tách thành phần tĩnh, động và tổng; đường ngang là ngưỡng T2B = 230 N·m và mô men liên tục 110 N·m của TPMA010S-055T.


Đường tăng tỉ số truyền thuần trong dòng DYNAMIC chỉ đủ ở khoảng $i=100$ và **sát ngưỡng mô men
liên tục** (do rotor nặng thêm), lại phụ thuộc tỉ số truyền có sẵn trong catalog nên kém chắc
chắn hơn.

## 7. Kết luận và ghi chú tích hợp

- Phân tích lực đã bổ sung đầy đủ theo yêu cầu trình bày: **sơ đồ phân bố lực** (Hình 1), **biểu
  đồ nội lực N/Q/M** (Hình 2), ký hiệu và công thức chuẩn hóa.
- Mô men động cơ được tính **tách tĩnh và động, có kể trọng lượng và quán tính bắp tay**, nhân
  **hệ số an toàn** $k_s=1{,}5$; $M_{động}$ tính lại theo từng hộp số qua $J_{rot}=J_{mot}i^2$.
- **TPM-010S-061T (T2B 80 N·m) không đủ** ($M_{yc}=112{,}5>80$) → chọn **TPMA 010S-055T
  (T2B 230 N·m)** cùng cỡ 010; kiểm chính thức: $M_{yc}=136{,}3 \le 230$ (dư 1,69×),
  $M_{rms}=53{,}4 \le 110$ (dư 2,06×), $30{,}1 \le 88$ vòng/phút — **đạt cả ba điều kiện**.
- **Tích hợp cơ khí — ĐÃ THAY vào mô hình CAD (2026-07-15):** đo trực tiếp hai mô hình CAD cho
  thấy giao diện lắp từ mặt bích ra về phía trước của TPMA **giống hệt** TPM cũ (bích Ø117,5×7,
  ngõng định tâm Ø90×9,6, pilot Ø63, mặt ra cách bích 30,0 mm) → **không phải sửa gá nào**
  (DR-002/003/004 giữ nguyên). Phần dài thêm 63,3 mm dồn hết về đuôi động cơ (vùng trống). Sau
  thay: vị trí mặt bích ra trùng khớp tuyệt đối (sai lệch 0,000 mm cả 3 tay) → thông số động học
  $R-r$ không đổi; kiểm giao thoa 504 = 504 vị trí (không phát sinh); khối lượng robot theo
  catalog tăng thêm 3×(8,1−4,9) = 9,6 kg về phía đế. Bằng chứng: `outputs/gearbox_swap_20260714/`.
- **FEA bền/độ võng không phải chạy lại**: bảng tải FEA sau khi thay hộp số **y nguyên**
  ($F_{ee}$ 175,8 N; thanh truyền 61,4 N; uốn bắp tay ~51 N·m) vì tải các khâu đến từ động lực
  học bàn máy (khối lượng chuyển động không đổi); phần $M_{động}$ tăng thêm dùng để gia tốc
  chính rotor bên trong hộp số, không truyền qua bích ra.

*Độ bảo thủ:* $J_{arm}$ dùng mô hình thanh mảnh đều (quán tính thực nhỏ hơn); $M_{tổng}$ cộng hai
đỉnh tĩnh–động (không luôn xảy ra đồng thời). Số thực thấp hơn đôi chút nhưng không đổi kết luận
vì biên vượt/đạt đều đủ lớn.

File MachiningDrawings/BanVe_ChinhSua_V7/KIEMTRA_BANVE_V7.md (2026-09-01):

# KIEM TRA BO BAN VE GIA CONG V7

Ngay kiem tra: 17/07/2026

Thu muc ban chinh sua: `F:\DeltaRobot\MachiningDrawings\BanVe_ChinhSua_V7`

## Noi dung da thuc hien

- Tao ban sao, khong ghi de file goc trong `F:\DeltaRobot\MachiningDrawings`.
- Bo khoi ghi chu `KICH THUOC GIA CONG CHINH` khoi vung hinh ve.
- Chuyen sang so do kich thuoc baseline va phan bo kich thuoc tren ba hinh chieu vuong goc.
- Giu hinh truc do 3D sach, khong dat kich thuoc.
- Loc kich thuoc nho, trung gia tri va trung instance; chi giu cac kich thuoc doc lap can thiet.
- Bo tri bon hinh tren luoi 2x2 A3 ngang, can deu khoang cach va tach khoi khung ten.

## Ket qua xuat va kiem tra truc quan

| Ban ve | SLDDRW | PDF | Kich thuoc tren 3 hinh chieu | Khong chong chu | Khong vuot khung |
|---|---:|---:|---:|---:|---:|
| DR-001-1_De-Gan-Tay | Dat | Dat | Dat | Dat | Dat |
| DR-001-2_Khung-Han | Dat | Dat | Dat | Dat | Dat |
| DR-001-3_Mat-Treo | Dat | Dat | Dat | Dat | Dat |
| DR-002_Motor-Bracket-A | Dat | Dat | Dat | Dat | Dat |
| DR-003_Motor-Bracket-B | Dat | Dat | Dat | Dat | Dat |
| DR-004_Shoulder-Bracket | Dat | Dat | Dat | Dat | Dat |
| DR-005-1_Upper-Arm-Hub | Dat | Dat | Dat | Dat | Dat |
| DR-005-2_Upper-Arm-Link | Dat | Dat | Dat | Dat | Dat |
| DR-006_Elbow-Clevis | Dat | Dat | Dat | Dat | Dat |
| DR-007_Moving-Platform | Dat | Dat | Dat | Dat | Dat |

Tong cong: 10 PDF, 10 SLDDRW, 10 log; tat ca log co `save drw err=0 pdf err=0` va `DONE2`.

## Luu y

Ban V7 chinh sua cach trinh bay ban ve, khong sua hinh hoc part nguon. Truoc khi phat hanh gia cong, nguoi phu trach cong nghe van nen xac nhan cac dung sai rieng, chuan dat va yeu cau be mat theo quy trinh cua xuong.

## Cap nhat 23/07/2026 - sua 2 loi khung ve/khung ten + tang co chu kich thuoc

Doi chieu voi `F:\DeltaRobot\Fomat\Rule_BanVe\khungve.png`, `khungten.png` va PDF TCVN 5705:1993
(muc luc dan chieu ISO R129:1959) phat hien 2 loi trong bo V7 cu, cong them 1 yeu cau bo sung ve co
chu kich thuoc, ca 3 da duoc sua trong CUNG mot lan chay lai script (`make_drawing_v7.ps1`), khong chay
lai rieng tung phan.

**Loi 1 - Khung vien sai margin.** Ban cu ve khung vien cach deu 10mm ca 4 canh. Theo `khungve.png`
(bang tra c/d cho khung A0-A4 nam ngang), canh TRAI (phia gay dong, ky hieu "d") phai = 25mm, 3 canh
con lai (tren/phai/duoi, ky hieu "c") = 10mm. Da sua: khung vien moi ve tai (25,10)-(410,10)-(410,287)-
(25,287) mm tren sheet A3 420x297mm. Vi khung trai dich vao 15mm, cot hinh chieu F/T (truoc o x=112mm)
duoc thu hep hanh lang kich thuoc va dich tam sang x=~119.5-121mm de khong lan khung; co kiem tra tu
dong qua `GetOutline` va tu dich them neu thieu (chua part nao can dich thuc te trong 10 part).

**Loi 2 - Khung ten sai hoan toan bo cuc.** Ban cu la bang 9 dong x 2 cot, kich thuoc ~166x58.5mm,
khong dung theo mau. Da thay bang dung `khungten.png`: bang **140mm x 32mm**, 5 cot (20/30/15/40/35mm)
x 4 hang (8/8/8/8mm), dat goc duoi-phai bang giay (trung khop canh phai/duoi cua khung vien moi).
O (1) Tua bai/ten goi vat the = merge (hang1+2, cot D+E); Nguoi ve/Kiem tra + ho ten/ngay o 2 hang dau
cot A/B/C; Truong/Lop merge cot A+B+C hang 3; Vat lieu merge cot D hang 3; Ti le/Ky hieu tach doi cot E
hang 3. Doi chieu voi anh mau: bo cuc luoi va vi tri 8 o noi dung khop voi `khungten.png`; rieng ranh
gioi chinh xac giua o "Vat lieu"/"Ti le"/"Ky hieu" trong anh mau khong co kich thuoc do rieng (chi co
140mm tong va 20/30/15mm cho 3 cot dau) nen phan chia 40mm/35mm cho 2 cot con lai la suy luan hop ly
duoc giu nguyen tu ban dau, khac biet duy nhat so voi mo ta ban dau cua nguoi dung.

**Yeu cau bo sung - co chu kich thuoc toi thieu 3.5mm + in dam.** TCVN 5705:1993 muc 2.3.1 cho phep
tu 2.5mm tro len nhung qua nho de doc ro khi in; da dat toi thieu **3.5mm** va **Bold=True** cho TOAN
BO annotation kich thuoc (khong chi mot phan) qua `IAnnotation.GetTextFormat(0)/SetTextFormat(0,false,tf)`
(mau chinh thuc SolidWorks dung de doi co chu hang loat) - khong tim thay API cap "document property"
truc tiep trong `swUserPreferenceIntegerValue_e` cho font kich thuoc (chi co cac thuoc tinh kieu mui
ten/duong dan), nen ap dung tung display-dimension annotation la cach dung API chinh thuc, ket qua
dong nhat 100% (khong lo dimension nao con font cu). Doc lai truoc/sau qua COM xac nhan chieu cao giu
nguyen 3.5mm (ban cu da san 3.5mm theo mac dinh chuan ve dang dung) va Bold: False->True tren tat ca
mau kiem tra.

**Chuan ghi kich thuoc**: kiem tra `GetUserPreferenceIntegerValue(13)` (swDetailingDimensionStandard)
truoc AutoDimension: ca 10 part deu DA San ISO (gia tri 2) tu truoc, khong can doi - phu hop voi TCVN
5705 (xay dung tren co so ISO R129:1959).

**Bang xac minh so lieu doc nguoc qua COM (10/10 part, chay 23/07/2026):**

| Ban ve | Khung vien mm (T/P/Tr/D) | Khung ten (rong x cao) | Chuan ghi KT | Co chu KT (mm/Bold) | 4 view khong vuot khung/khung ten | Save/PDF |
|---|---|---:|---:|---:|---:|---:|
| DR-001-1_De-Gan-Tay | 25/10/10/10 | 140.00 x 32.00 | ISO(2) | 3.5 / True (109 annotation) | ALL PASS | err=0/0, 62.4KB |
| DR-001-2_Khung-Han | 25/10/10/10 | 140.00 x 32.00 | ISO(2) | 3.5 / True (78 annotation) | ALL PASS | err=0/0, 42.1KB |
| DR-001-3_Mat-Treo | 25/10/10/10 | 140.00 x 32.00 | ISO(2) | 3.5 / True (109 annotation) | ALL PASS | err=0/0, 47.5KB |
| DR-002_Motor-Bracket-A | 25/10/10/10 | 140.00 x 32.00 | ISO(2) | 3.5 / True (35 annotation) | ALL PASS | err=0/0, 39.3KB |
| DR-003_Motor-Bracket-B | 25/10/10/10 | 140.00 x 32.00 | ISO(2) | 3.5 / True (49 annotation) | ALL PASS | err=0/0, 41.1KB |
| DR-004_Shoulder-Bracket | 25/10/10/10 | 140.00 x 32.00 | ISO(2) | 3.5 / True (31 annotation) | ALL PASS | err=0/0, 43.9KB |
| DR-005-1_Upper-Arm-Hub | 25/10/10/10 | 140.00 x 32.00 | ISO(2) | 3.5 / True (35 annotation) | ALL PASS | err=0/0, 48.8KB |
| DR-005-2_Upper-Arm-Link | 25/10/10/10 | 140.00 x 32.00 | ISO(2) | 3.5 / True (6 annotation) | ALL PASS | err=0/0, 36.0KB |
| DR-006_Elbow-Clevis | 25/10/10/10 | 140.00 x 32.00 | ISO(2) | 3.5 / True (68 annotation) | ALL PASS | err=0/0, 47.1KB |
| DR-007_Moving-Platform | 25/10/10/10 | 140.00 x 32.00 | ISO(2) | 3.5 / True (91 annotation) | ALL PASS | err=0/0, 49.1KB |

Cot "4 view khong vuot khung/khung ten" = doc `IView.GetOutline` cho ca 4 hinh (Front/Top/Side/Iso)
ngay sau khi dat vi tri view cuoi cung (diem doc tin cay duy nhat tren may nay - xem bay COM ben duoi),
so sanh voi toa do khung vien va bbox khung ten muc tieu; ca 40 view (10 part x 4) deu PASS.

**Bay COM phat hien them trong phien nay (bo sung vao ghi chu CLAUDE.md/memory)**: `IView.GetOutline`
tra ve dung hoac sai KHONG PHAI do tien trinh SolidWorks "stale" hay can mo lai file trong process rieng
nhu nghi ban dau - do la mot con duong sai lam ton nhieu thoi gian dieu tra. Nguyen nhan that su la
**bug trong chinh script PowerShell**: PowerShell coi ten bien KHONG PHAN BIET HOA/THUONG, nen
`$oxm` va `$oxM` la CUNG MOT bien - gan `$oxM=$ol[2]` da de len gia tri `$oxm=$ol[0]` truoc do, khien
ca 4 gia tri in ra deu trung voi xmax/ymax that. Sua bang cach dat ten bien phan biet hoan toan
(`$vLeft/$vBottom/$vRight/$vTop`). Bai hoc: KHONG dat 2 bien chi khac nhau o chu hoa/thuong trong cung
script (vi du toi da tung dung `$oxm`/`$oxM`, `$oym`/`$oyM`).

## Cap nhat 23/07/2026 (phan 2) - dong bo khung ten/khung vien theo mau tay nguoi dung (DR-001-3)

Sau lan chay script o phan 1, nguoi dung mo truc tiep `DR-001-3_Mat-Treo.SLDDRW` trong SolidWorks (KHONG
qua script) va tu tay chinh khung ten - coi day la ban CHUAN. Nhiem vu: doc chinh xac khung ten/khung
vien cua DR-001-3 roi ap dung y het sang 9 ban ve con lai, TUYET DOI KHONG dong vao dimension tren cac
view.

**Doc nguoc DR-001-3 (file `.claude`/kich hoat doc doc dung `SwRaw`/typed interop, mo `OpenDoc6` type=3):**
File dang KHONG mo trong bat ky tien trinh SolidWorks nao luc kiem tra (`ISldWorks.GetDocuments` rong,
ROT chi co 1 tien trinh `SolidWorks_PID_13364`, khong co lock file `~$...`), nen mo bang `OpenDoc6` voi
`Options=1` (READ-ONLY), doc xong dong lai KHONG luu - dung theo yeu cau. Khung vien (`Sketch1`, 4 doan
thang duoi Sheet1) = **(25,10)-(410,10)-(410,287)-(25,287) mm - GIONG HET mac dinh cua script** (khong
doi). Bang ten la mot **`GeneralTableFeature`** ten "General Table1" (tim qua duyet cay tinh nang de quy
`GetFirstSubFeature`/`GetNextSubFeature`, roi unwrap qua `IGeneralTableFeature.GetTableAnnotations()` -
`Feature.GetSpecificFeature2()` tren mot GeneralTableFeature KHONG tra ve thang TableAnnotation nhu tuong,
phai qua buoc unwrap nay). Bo cuc bang **CUNG HET** voi mac dinh cua script (140x32mm, 5 cot 20/30/15/40/35,
4 hang 8/8/8/8, cung vi tri neo goc duoi-phai x=270mm y=42mm, cung kieu merge, cung can giua ngang,
cung BorderLineWeight/GridLineWeight/AnchorType) - nguoi dung KHONG doi bo cuc/khung vien, chi doi
**dinh dang chu trong o va noi dung o "Tua bai"**:
- Chieu cao chu tung o (per-cell, khong phai muc mac dinh cua bang): script cu = 2.200mm (khong Bold,
  `useDocFmt=True` - ke thua dinh dang bang); DR-001-3 = **2.38125mm = 6.75pt chinh xac** (da xac minh
  qua tinh nguoc 6.75 x 0.352778mm/pt = 2.38125mm khop tuyet doi voi so doc duoc), ap dung rieng cho
  TUNG o (`useDocFmt=False`) - khong con ke thua muc mac dinh cua bang.
- Can chinh doc trong o (vertical justification): script cu = Middle (2) cho tat ca o; DR-001-3 =
  **Top (1)** cho tat ca o.
- O "Tua bai" (o gop (0,3)-(1,4)): script cu ghi text tho la ten file (vd `DR-002_Motor-Bracket-A`);
  DR-001-3 dung dinh dang rich-text gan lien: `<FONT size=14PTS style=B>DR-001-3: Mat-Treo` - tuc la
  **the HTML-like `<FONT size=14PTS style=B>` (14pt, in dam) + noi dung "MA: Mo-ta"** (thay dau `_` dau
  tien bang `: `, giu nguyen dau `-` trong phan mo ta).
- Khong doi: font family (Century Gothic - ke thua template, khong phai script dat), width factor 0.8,
  can chinh ngang (Center), TitleVisible=False, vi tri neo bang, khung vien, cac o noi dung khac (vat
  lieu/ti le/ma hieu/nguoi ve.../ngay...) van giu dung logic rieng cua tung part (khong copy cung noi
  dung cua DR-001-3 sang cac file khac).

**Cach dong bo (khong xoa-tao-lai bang/khung vien)**: vi khung vien VA bo cuc bang (kich thuoc cot/hang,
vi tri neo, kieu merge) o ca 9 file da GIONG HET DR-001-3 tu truoc (do ca 10 file cung duoc script sinh
trong CUNG mot lan chay o phan 1), viec "xoa khung cu, dung khung moi" tuong duong ve mat ket qua voi
**sua tai cho (in-place) 3 thuoc tinh khac biet da neu tren** - cach nay AN TOAN HON xoa/tao lai vi
khong dong den ma bang/khung vien dang lien ket voi cac view, giam rui ro lam lech dimension. Da kiem
tra: 2 file `DR-001-1_De-Gan-Tay` va `DR-001-2_Khung-Han` truoc do da bi chinh tay mot phan (khac voi
8 file con lai) - vi du DR-001-1 co san chieu cao chu 2.1167mm/wf=1.0/o Tua bai la "De Gan Tay" (khong
dau gach ngang, chu Bold=True truc tiep tren dinh dang o, KHONG co the `<FONT>`); DR-001-2 co san the
`<FONT size=14PTS>` (khong co `style=B`). Ca hai deu duoc ghi de ve dung 1 chuan DR-001-3 duy nhat trong
lan chay nay, dam bao dong nhat tuyet doi tren toan bo 9 file.

**Script su dung**: `sync_titleblock.ps1` (luu scratchpad phien lam viec) - moi file: mo (khong read-only,
type=3 options=0), `ActivateDoc3`, doc dem so dimension moi trong 4 view qua `GetDimensionCount4` (baseline
TRUOC), tim feature "General Table1" -> unwrap TableAnnotation, ap dung `SetCellTextFormat(r,c,false,tf)`
voi `tf.CharHeight=0.00238125` + `tf.WidthFactor=0.8` + `tf.Bold=false` va `set_CellTextVerticalJustification(r,c,1)`
cho toan bo 20 o (4x5), rieng o (0,3) ghi text moi theo mau MA/Mo-ta cua tung file, `ForceRebuild3`, dem
lai dimension (SAU), so sanh voi baseline - neu lech se DUNG NGAY khong luu (chua gap truong hop nao lech
trong 9 file); neu khop thi `SaveAs4` de ghi de SLDDRW + xuat PDF cung ten. Backup 9 file da co san tu
truoc (`*_backup_20260723_pretitleblocksync.SLDDRW`), khong tao them.

**Bang xac minh 10/10 part (doc nguoc qua COM, chay 23/07/2026 12:2x):**

| Ban ve | Khung ten khop mau (H=2.38125mm/Top/font tag) | Khung vien khop mau (25/10/10/10) | Dimension count (truoc=sau, tung view) | PDF export |
|---|---|---|---|---:|
| DR-001-1_De-Gan-Tay | Dat | Dat | 3=3, 2=2, 2=2, 0=0 | err=0, 76 638B |
| DR-001-2_Khung-Han | Dat | Dat | 3=3, 2=2, 2=2, 0=0 | err=0, 51 065B |
| DR-001-3_Mat-Treo (mau, khong sua) | - (mau goc) | - (mau goc) | khong doi (khong mo ghi) | err=0, 64 102B |
| DR-002_Motor-Bracket-A | Dat | Dat | 4=4, 3=3, 3=3, 0=0 | err=0, 48 143B |
| DR-003_Motor-Bracket-B | Dat | Dat | 4=4, 3=3, 3=3, 0=0 | err=0, 49 693B |
| DR-004_Shoulder-Bracket | Dat | Dat | 4=4, 3=3, 1=1, 0=0 | err=0, 52 764B |
| DR-005-1_Upper-Arm-Hub | Dat | Dat | 4=4, 3=3, 3=3, 0=0 | err=0, 57 887B |
| DR-005-2_Upper-Arm-Link | Dat | Dat | 2=2, 2=2, 0=0, 0=0 | err=0, 45 309B |
| DR-006_Elbow-Clevis | Dat | Dat | 2=2, 2=2, 3=3, 0=0 | err=0, 55 840B |
| DR-007_Moving-Platform | Dat | Dat | 2=2, 3=3, 1=1, 0=0 | err=0, 58 532B |

Tat ca 9 file sua deu: `dimMatch=True`, `borderMatch=True` (toa do 4 doan thang khung vien doc lai SAU
edit giong het TRUOC edit), `saveErr=0`, `pdfErr=0`. File `DR-001-3_Mat-Treo.SLDDRW` xac nhan KHONG bi
ghi de (size/timestamp giu nguyen 220 954B / 12:06:42 truoc va sau khi xuat lai PDF).

## Cap nhat 23/07/2026 (phan 3) - khoi phuc ky hieu ren + lam day lai bo kich thuoc bi loc qua tay

**Van de nguoi dung bao**: 10 ban ve V7 (phan 1+2) THIEU ky hieu ren (M5, M20, M16, M2.5, M48, INCH TAP)
tren cac lo ren that, trong khi mot file tham chieu con sot lai `DR-003_Motor-Bracket-B_RenM20.SLDDRW`
co hien thi dung kieu ky hieu nguoi dung muon. Sau do nguoi dung bo sung them file tham chieu day du
`BaoCao/Ban ve gia cong/GiaCongCoKhi.pdf` (10 trang, khung ten/khung vien kieu CU khong dung, nhung NOI
DUNG kich thuoc + ren la muc tieu) va yeu cau mo rong: khoi phuc luon ca bo kich thuoc day du bi bo loc
V7 (dong ~396-456 trong `make_drawing_v7.ps1`) an bot qua tay (limit 2-4 dim/view), khong chi rieng ren.

**Buoc 1 - xac dinh dung "ky hieu ren" la loai annotation gi (doc file tham chieu, KHONG mo ghi)**:
Mo `DR-003_Motor-Bracket-B_RenM20.SLDDRW` bang `OpenDoc6` Options=1 (read-only), duyet `IView.GetAnnotations()`
tung view (KHONG phai `IModelDocExtension.GetAnnotations()` - ham nay tra ve rong cho drawing, phai lay o
cap VIEW). Ket qua: chu "2X M20 X 2.5⌵20" **KHONG PHAI** la `IDisplayDimension`/hole-callout tu AutoDimension
(kiem tra toan bo dim trong file: `IDisplayDimension.IsHoleCallout()` deu tra ve **False**, khong co dim nao
gan voi duong kinh lo ren) - ma la **mot `IAnnotation` loai NOTE (annType=6) danh rieng, tay them**, noi
dung tho luu trong model: `'2X M20 X 2.5 <HOLE-DEPTH>20'`, trong do the `<HOLE-DEPTH>` la ky hieu thu vien
chuan cua SolidWorks (render thanh dau V/rot xuong bieu thi "chieu sau"). Vay nguyen nhan goc: **ky hieu ren
CHUA TUNG duoc AutoDimension sinh ra** (khong phai bi an) - phai tao moi bang NOTE dung mau nay, khong
phai bat lai `Visible`.

**Buoc 2 - xac minh THAT co lo ren nao qua COM tren tung part (khong tin danh sach tham chieu mu quang)**:
Doc `IFeature.GetDefinition()` ep kieu `ThreadFeatureData` (feature loai `SweepThread` - Insert>Features>
Thread that, KHAC voi cac feature dat ten `LoRen-*/LoBac-*` chi la Cut-Extrude thuong danh dau bang ten
Viet). Truong `Type`/`Size` cho dung ten ky hieu ren SolidWorks tu dung (vd `M20x2.5`, `0.6250-18`); truong
`Pitch`/`BlindDepth`/`Revolutions` **KHONG dang tin cay** qua API nay (doc ra dong loat 10.000mm bat ke
kich thuoc that - nghi la gia tri "template" cua thu vien profile, khong phai gia tri da ap dung) - rieng
`BlindDepth` cho 4 thread tren DR-002 lai doc dung (20/20/15/8mm, khac nhau ro giua cac feature) nen van
dung duoc cho truong hop nay; cho cac feature M48/INCH TAP khac deu doc ra 10mm dong loat (khong dung), nen
**gia tri chieu sau dung trong ghi chu cuoi cung lay tu file tham chieu PDF** (30mm cho M48, 40mm cho INCH
TAP - nhat quan qua nhieu part, hop ly hon so voi con so 10mm doc lech tu API).

**Ket qua xac minh 10/10 part (bang lo ren THAT, doc qua `FirstFeature`/`GetNextFeature` + `ThreadFeatureData`):**

| Part | Feature ren that (SweepThread) | Ky hieu chinh xac | Ghi chu ren them vao ban ve |
|---|---|---|---|
| DR-001-1_De-Gan-Tay | khong co | - | KHONG them (khong co ren that; theo dung file tham chieu) |
| DR-001-2_Khung-Han | khong co SweepThread (co LoRen-M12-Pad-x6/LoRen-M12-Goc-x3 nhung chi la Cut-Extrude danh dau ten, khong phai Thread that) | - | KHONG them (theo yeu cau tuong minh cua nguoi dung: giu dung file tham chieu, file do khong ghi ren cho cac lo M12/M16/M20 cua khoi DR-001) |
| DR-001-3_Mat-Treo | tuong tu DR-001-2 (LoBat-M16-x9/LoVit-M20-x6 la Cut-Extrude, khong phai Thread that) | - | KHONG them (tuong minh theo tham chieu) |
| DR-002_Motor-Bracket-A | Thread10/11=M20x2.5 (sau=20mm), Thread14/15=M16x2.0 (sau=15/8mm - 2 ban sao lech nhau, xem luu y) | M20x2.5, M16x2.0 | **"2X M20 X 2.5⌵20"** + **"2X M16 X 2.0⌵8"** (view Top) |
| DR-003_Motor-Bracket-B | Thread2/Thread3=M20x2.5 (sau=20mm, qua LPattern1/LPattern4) | M20x2.5 | **"2X M20 X 2.5⌵20"** (dat ca 2 view Front+Top, dung y het file tham chieu goc) |
| DR-004_Shoulder-Bracket | khong co SweepThread (chi Cut-Extrude Ø2.6 THRU + Ø5 CBORE - ren that nam ben DR-005-1) | - | KHONG them (dung nhu CLAUDE.md mo ta) |
| DR-005-1_Upper-Arm-Hub | Thread3=M48x3.0 (1 lan, khong pattern); LoRen-M25-Hub-x8 la Cut-Extrude (khong phai Thread that nhung ten feature xac nhan la lo ren tap Ø2.05x8) | M48x3.0, M2.5x0.45 | **"M48 X 3.0⌵30"** + **"8X M2.5 X 0.45⌵8"** |
| DR-005-2_Upper-Arm-Link | Thread1=M48x3.0, Thread2=**M48x5.0** (2 dau thanh giang, KHAC buoc ren nhau - xem luu y) | M48x3.0, M48x5.0 | **"M48 X 3.0⌵30"** + **"M48 X 5.0⌵30"** |
| DR-006_Elbow-Clevis | Thread1=M48x3.0 (1 lan); Thread2=0.6250-18 qua Mirror6 (2 lan) | M48x3.0, 5/8-18 UNF | **"M48 X 3.0⌵30"** + **"2X 5/8-18 UNF⌵40"** |
| DR-007_Moving-Platform | Thread1+Thread2=0.6250-18 qua Mirror1+CirPattern1 (6 lan tren 3 canh x 2 khop cau) | 5/8-18 UNF | **"6X 5/8-18 UNF⌵40"** |

**Luu y CAD phat hien duoc trong qua trinh xac minh (khong tu sua CAD, chi bao cao)**: (1) DR-002 co 2 ban
sao Thread14/Thread15 cung danh nghia M16x2.0 nhung `BlindDepth` doc duoc lech nhau (15mm vs 8mm) - da
dung gia tri 8mm (khop voi tham chieu) cho ghi chu, nhung day co the la loi nhap lieu CAD can nguoi
huong dan/nguoi dung kiem tra lai truc tiep tren feature Thread14. (2) DR-005-2 (Upper-Arm-Link) co
Thread1=M48x3.0 va Thread2=M48x5.0 - hai dau thanh giang mang **buoc ren khac nhau** (3.0 vs 5.0mm) trong
khi ve mat lap ghep (noi voi DR-005-1 hub va DR-006 elbow-clevis, ca hai deu dung M48x3.0) thi ca hai dau
nen giong nhau; nhieu kha nang Thread2 bi nhap sai buoc ren luc tao feature - **can nguoi dung/GVHD xac
nhan lai truc tiep tren CAD**, ban ve hien dang phan anh DUNG trang thai CAD hien tai (khong tu y sua).

**Buoc 3 - mo rong theo yeu cau: lam day lai bo kich thuoc day du (khong chi rieng ren)**: bo loc V7 goc
(ham tinh diem theo `Type2`, gioi han `$limit` = 2-4 dim/view) van con nguyen trong file (dim bi an qua
`SetAnnotationVisible(...,false)`, KHONG bi xoa). Da viet lai thuat toan: doc lai TOAN BO `GetDisplayDimensions`
(ca dang an), **giu nguyen tat ca dim dang hien (khong bao gio an bot - chi duoc phep THEM)**, roi nang
`limit` len 6/view va cho phep them cac dim bi an co diem so cao nhat (dedup theo `Type2+GiaTri`, khong
trung lap gia tri qua nhieu view) duoc hien lai, cho den khi dat 6 hoac het luoc. **Khong dung cach "bat
lai tat ca"** vi kiem tra rieng cho thay `DR-001-3` view Top co toi **96 dim tho** (AutoDimension ghi rieng
tung lo trong bo 9xM16+6xM20 theo so do "chain", moi lo mot gia tri khac nhau, khong the dedup) - bat het
se ra ban ve roi khong doc duoc; nang gioi han len 6/view (thay vi bat het) giu duoc dung cac gia tri PHAN
BIET quan trong (kiem chung: bang kich thuoc doc lai khop rat sat voi tham chieu PDF cho DR-001-1/-2/-3,
xem vi du duoi).

**Vi du doi chieu voi tham chieu PDF (khong bat buoc khop tuyet doi vi hinh hoc da doi qua nhieu lan sua
doi xung/tach khoi - chi can DUNG LOAI kich thuoc)**: DR-001-1 sau khi lam day: 755.92/315.82/317.48,
9XR24/3XR26/3XR28, 3XR381/3XR383, 723.39/777.94, Fillet 2mm - khop hau het cac gia tri tham chieu neu
(chi thieu 82mm day thay vi "50" - do hinh hoc that la 82mm, tham chieu co the da cu). DR-001-3: 252.19,
153.00, 52.98, 3XR383.03, Ø150 THRU, Ø17.5, R129.92, 38.25, 259.77, 77.22 - khop gan nhu toan bo danh sach
tham chieu.

**Script**: `fix_ren_and_dims.ps1` (luu scratchpad phien lam viec) - moi file: mo (khong read-only), doc
BEFORE (dump khung ten qua `GeneralTableFeature`->`GetTableAnnotations()`, dem dim total/visible tung view),
nang limit dim + them NOTE ren (co bao ve trung lap theo cap (view,text) de chay lai an toan, khong tao
note trung), rebuild, doc AFTER, so sanh khung ten TRUOC=SAU (bang chuoi dump tung o), luu `SaveAs4` de
SLDDRW + xuat PDF. Vi tri dat NOTE: tu dong chon view co nhieu dim duong kinh/ban kinh nhat (`Type2`=5
hoac 6 - dai dien view nhin thang mat lo tron), dat trong "hanh lang kich thuoc" co san cua tung view
(cung toa do co dinh dung trong `make_drawing_v7.ps1`), khong dam vao khung vien/khung ten.

**Bang xac minh cuoi cung 10/10 part (doc nguoc qua COM sau khi luu, script `final_verify.ps1`):**

| Ban ve | Khung vien (25/10/10/10mm) | Khung ten | Ren that + so luong | Ky hieu ren them | Dim total/visible (3 view chinh) |
|---|---:|---:|---|---|---|
| DR-001-1_De-Gan-Tay | Dat, khong doi | Dat, khong doi | Khong | (khong co) | 18/6, 71/6, 19/6 |
| DR-001-2_Khung-Han | Dat, khong doi | Dat, khong doi | Khong (theo tham chieu) | (khong co) | 4/4, 70/6, 4/2 |
| DR-001-3_Mat-Treo | Dat, khong doi | Dat, khong doi (mau tay nguoi dung giu nguyen) | Khong (theo tham chieu) | (khong co) | 8/6, 96/6, 6/5 |
| DR-002_Motor-Bracket-A | Dat, khong doi | Dat, khong doi | Co: 16xM5 (Cut, khong Thread), 2xM20x2.5, 2xM16x2.0 | 2X M20 X 2.5⌵20 + 2X M16 X 2.0⌵8 | 12/6, 14/6, 9/6 |
| DR-003_Motor-Bracket-B | Dat, khong doi | Dat, khong doi | Co: 2xM20x2.5 | 2X M20 X 2.5⌵20 (x2 view, khop tham chieu) | 27/6, 10/6, 12/6 |
| DR-004_Shoulder-Bracket | Dat, khong doi | Dat, khong doi | Khong (xac nhan qua COM: khong co SweepThread) | (khong co) | 5/4, 21/6, 5/1 |
| DR-005-1_Upper-Arm-Hub | Dat, khong doi | Dat, khong doi | Co: 1xM48x3.0, 8xM2.5 (Cut) | M48 X 3.0⌵30 + 8X M2.5 X 0.45⌵8 | 17/6, 10/6, 8/4 |
| DR-005-2_Upper-Arm-Link | Dat, khong doi | Dat, khong doi | Co: 1xM48x3.0, 1xM48x5.0 | M48 X 3.0⌵30 + M48 X 5.0⌵30 | 2/2, 2/2, 2/0 |
| DR-006_Elbow-Clevis | Dat, khong doi | Dat, khong doi | Co: 1xM48x3.0, 2x5/8-18 UNF | M48 X 3.0⌵30 + 2X 5/8-18 UNF⌵40 | 20/6, 28/6, 20/6 |
| DR-007_Moving-Platform | Dat, khong doi | Dat, khong doi | Co: 6x5/8-18 UNF | 6X 5/8-18 UNF⌵40 | 22/6, 42/6, 27/6 |

Tat ca 10 file: `save drw err=0`, `pdf err=0`; khung vien doc lai dung 4 doan `(25,10)-(410,10)-(410,287)-
(25,287)` mm cho ca 10 file; khung ten doc lai (dump toan bo 20 o) GIONG HET truoc/sau moi lan sua (chi
sua dim + them note, khong dung toi feature `GeneralTable1`). Backup truoc khi sua da co san tu truoc
(`Backup/*_backup_20260723_beforerensymbol.SLDDRW`, tao boi phien truoc).

**Han che con lai (bao cao trung thuc, khong che giau)**: mot vai vi tri ghi chu ren/kich thuoc dat gan
nhau bi chong nhe (vd DR-005-1 "8X M2.5..." cham vao so "82.71"; DR-006/DR-007 "M48.../INCH TAP..." cham
nhe vao mot dim khac) - van doc duoc ro rang tung so nhung chua toi uu hoan toan ve mat bo tri; can tinh
chinh vi tri tung note thu cong neu muon dep tuyet doi cho ban in cuoi cung. Depth cua ren M48/INCH TAP
(30mm/40mm) lay tu file tham chieu PDF (API `BlindDepth` khong dang tin cay cho cac feature nay) - neu
GVHD yeu cau do chinh xac tuyet doi thi nen do lai truc tiep tren feature CAD (Edit Feature > Thread) roi
sua text NOTE tuong ung (khong anh huong toi cach lam, chi thay so).

## Cap nhat 23/07/2026 (phan 4) - sua chong chu do buoc "lam day kich thuoc" o phan 3 gay ra

**Van de nguoi dung phat hien (doc truc tiep PDF, khong chi tin log)**: buoc "nang limit dim tu 2-4 len 6/
view" o phan 3 chi doi `Visible=true/false`, KHONG bao gio goi lai buoc sap xep vi tri (`SetPosition`) -
nen cac dim vua duoc hien lai van nam nguyen o vi tri AutoDimension dat tu dau (rat sat nhau khi so luong
dim/view tang tu 2-4 len 6), sinh ra chu de len nhau ro nhat o `DR-006` (4 cho: "96.25/94.49" dinh vao
nhau, "75.89/75.91/76.84" chong lam mot, "92.96 94.73 119.27 120.51 21.00 122.51" dinh chuoi, ghi chu ren
de len dim khac) va `DR-007` ("267.20/267.21" + "269.15/269.16" gan trung gia tri dinh chuoi, ren de len
"R20.48"); `DR-005-1`/`DR-002` nhe hon nhung van co cho cham.

**Nguyen nhan hai lop, sua theo dung 2 buoc nguoi dung yeu cau:**

**(1) Gop dimension gan trung gia tri** (< 1mm, cung `Type2`, cung 1 view): mot phan nguyen nhan la
AutoDimension tu sinh 2 dim GAN NHU giong het gia tri tu 2 canh doi xung (vd 267.20 vs 267.21, chenh
0.01mm - do sai so lam tron hinh hoc doi xung) ma buoc loc phan 3 (dedup theo khoa `Type2|Round(val,2)`)
khong bat duoc vi 267.20 va 267.21 lam tron o 2 chu so thap phan ra 2 khoa KHAC nhau. Sua: doi sang so
sanh **hieu tuyet doi < 1.0mm** giua cac gia tri da sap xep trong cung nhom `Type2` cua tung view (khong
con phu thuoc lam tron) - AN NGAY cac ban trung: `DR-007` an 267.205→giu 267.203, an 269.157→giu 269.155;
`DR-006` an 75.907 va 76.841→giu 75.888 (gop ca 3 gia tri gan nhau lien tiep thanh 1); `DR-003` an 2 cap
R17/R19 gan D-002; `DR-002`, `DR-004`, `DR-005-1` moi noi an 1 cap. Ap dung cho toan bo 10 file, khong
rieng DR-006/DR-007.

**(2) Sap xep lai vi tri sau khi loc** (nguyen nhan chinh gay chong chu): viet lai thuat toan "dim arrange"
cua ban goc (`make_drawing_v7.ps1` dong ~459-506, von chi chay MOT LAN luc tao ban ve dau tien voi it dim
hon) thanh script rieng `fix_overlap.ps1`, chay LAI tren toan bo dim+note DANG HIEN trong tung view:
- Phan loai tung nhan (dimension hoac ghi chu ren) vao 1 trong 5 vung quanh view (`left/right/above/below/
  inside`) theo vi tri so voi `GetOutline` cua view.
- **Phat hien va sua 1 loi mo hinh sai ban dau**: dim dat o `left`/`right` (hai ben view) trong SolidWorks
  duoc **xoay 90° de doc theo chieu doc** (chuan cua SW cho dim thang dung) - lan sua dau tien coi nham
  chieu "dai" cua khoi chu la chieu ngang (theo do rong chuoi ky tu) giong dim ngang, khien khoang cach
  giua cac shelf xep chong qua gan (chinh la nguyen nhan can 2 vong sua truoc khi phat hien, vd DR-005-1:
  "80.73"/"43.00" bi dinh o view Side). Sua: gan `HalfX`/`HalfY` moi nhan theo **dung huong doc chu that**
  (dim trai/phai: truc dai = Y dung do dai chuoi; dim tren/duoi + ghi chu ren: truc dai = X).
  - Xep tung vung theo kieu "shelf" (nhu xep sach): sap xep theo truc chinh, moi nhan chiem it nhat
    `do_dai_chu/2 + do_dai_chu_ke/2 + khe_ho(4.5mm)`; neu khong du cho tren 1 hang, tu dong mo hang moi
    (dich ra xa view them 1 buoc co dinh ~5.25mm) - dam bao KHONG BAO GIO 2 nhan chen nhau tren cung true
    chinh du so luong dim tang len bao nhieu.
  - **Ghi chu ren duoc danh rieng 1 "bang" o mep tren/duoi cua o luoi** (khong con canh tranh cho voi dim
    khac) - day chinh la nguyen nhan lam ghi chu ren "8X M2.5..." de len dim "82.71"/"R42.00" trong 2 lan
    sua dau (chung dung chung 1 hang xep va giao tranh nhau); tach rieng ra 1 dai danh rieng cho ren, con
    dim duoc xep trong phan con lai cua o luoi → het chong hoan toan.
  - Sau khi xep, chay them **1 buoc don doc-va-sua lap** (`Resolve-Overlaps`, toi da 20 vong): doc lai vi
    tri THAT + uoc luong kich thuoc chu that (so ky tu × 0.78×chieu cao chu 3.5mm, co tinh chu Bold rong
    hon chu thuong) cho tung nhan, kiem tra tung cap, neu con cham thi day nhan ra xa dung huong con thieu
    it nhat - lam viec doc lap voi buoc xep-shelf ben tren, bat duoc moi truong hop con sot du nguyen nhan
    la gi.

**Xac minh bang so lieu (khong chi nhin anh), script `fix_overlap.ps1` tu doc lai SAU khi luu, toan bo
10/10 file, chay lai them 1 lan cuoi voi khe ho rong hon (4.5mm, uoc luong chu rong hon cho font Bold) de
kiem tra chat hon:**

| Ban ve | Dedup gia tri trung (<1mm) | Buoc xep lai (left/right/above/below/inside, tung view) | Bbox check con cham? | Khung ten/khung vien | Save/PDF |
|---|---|---|---|---|---|
| DR-001-1_De-Gan-Tay | 0 | 0/4,3/3,2/1 | Khong | Khong doi | err=0/0 |
| DR-001-2_Khung-Han | 0 | 2/2,3/3,2/0 | Khong | Khong doi | err=0/0 |
| DR-001-3_Mat-Treo | 0 | 1/4,3/2,3/1 | Khong | Khong doi | err=0/0 |
| DR-002_Motor-Bracket-A | 1 (122.33≈121.42) | 2/2,3/3,3/3 | Khong | Khong doi | err=0/0 |
| DR-003_Motor-Bracket-B | 2 (R17,R19 doi) | 2/2,3/3,4/2 | Khong | Khong doi | err=0/0 |
| DR-004_Shoulder-Bracket | 1 (Ø2.6≈Ø2.59) | 3/1,1/4,1/0 | Khong | Khong doi | err=0/0 |
| DR-005-1_Upper-Arm-Hub | 1 (100.37≈100.23) | 4/0,4/1,4/0 | Khong (sau khi tach rieng bang ren) | Khong doi | err=0/0 |
| DR-005-2_Upper-Arm-Link | 0 | 2/0,0/2,0/0 | Khong | Khong doi | err=0/0 |
| DR-006_Elbow-Clevis | 3 (75.91,76.84 gop vao 75.89) | 3/0,0/4,2/4 | Khong | Khong doi | err=0/0 |
| DR-007_Moving-Platform | 2 (267.21,269.16 gop) | 1/2,1/5,0/3 | Khong | Khong doi | err=0/0 |

Tat ca 10 file: `TITLE TABLE UNCHANGED=True` (dump 20 o khung ten giong het truoc/sau), khung vien khong
dong den (script khong chua bat ky lenh nao sua sketch khung vien), `ANY OVERLAP REMAINING=False` qua
kiem tra bbox uoc luong, `save drw err=0`, `pdf err=0` ca 10 file. Kiem tra lai bang mat qua PDF xac nhan
DR-006 va DR-007 (2 file te nhat) gio doc ro tung so, khong con dam vao nhau.

**Han che con lai (bao cao trung thuc)**: uoc luong be rong chu dua tren so ky tu × he so trung binh
(khong doc truc tiep font-metrics that cua SolidWorks vi API khong lo ra), nen 1 vai cho VAN con nhan sat
nhau trong pham vi vai mm (duoi nguong bbox uoc luong nhung nhin ky van co the thay hoi cham leader-line
hoac 2 so cach nhau ~1-2mm) - cu the: `DR-006` view duoi-trai "92.96/94.73" va "119.27/120.51/122.51" (3
kich thuoc that su khac nhau 1-2mm, khong phai trung lap nen khong the gop, chi con cach tach thanh nhieu
hang hon hoac doi ty le ban ve); `DR-005-1`, `DR-002`, `DR-004` co leader-line di ngang qua gan chu (khong
lam mat so, chi hoi roi mat) o 1-2 vi tri. Day la muc do "co the chap nhan duoc cho do an gia cong" chu
chua phai "hoan hao tuyet doi tung pixel" - neu can dep hon nua thi phai chinh tay tung annotation hoac
giam so luong dimension quay lai (danh doi giua "day du thong tin" va "khong khi nao cham nhe").

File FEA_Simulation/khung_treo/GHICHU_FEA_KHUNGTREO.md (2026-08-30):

# FEA khung treo robot (Frame.SLDPRT) — ghi chú kết quả

**Ngày:** 2026-07-22. **Part:** `DeltaRobot_Final/Frame.SLDPRT` (khung thép ASTM A36, 643 kg, 1 solid).

## Mô hình
- **Ngàm:** 4 mặt đáy chân đế (Y = −2650), fixed. (faces F49/F27/F55/F66)
- **Tải:** trọng lượng robot treo = m·g·k = 140 kg × 9.81 × 1.5 ≈ **2060 N** hướng xuống (−Y), đặt trên mặt đĩa treo (3 mảng đỉnh đĩa Ø720). Ref face F2 (đáy Y−177.8).
- **Lưới:** solid parabolic, quét 6 mm và 12 mm.
- Vật liệu A36, giới hạn chảy σ_y = 250 MPa.

## Kết quả
| Lưới | von Mises max (MPa) | Ghi chú |
|---|---|---|
| 6 mm  | 350 | đỉnh tại điểm đặt tải |
| 12 mm | 224 | đỉnh GIẢM khi lưới thô hơn |

- **Phổ ứng suất toàn khung = XANH (thấp)** trên toàn bộ cột/vành/nan — xem `figs/fea_khungtreo_final_vonMises.png`. Chỉ có điểm nóng cục bộ ngay tại mặt đặt tải.
- **Biến dạng thực ≈ 0,6–0,8 mm** (suy từ hệ số phóng đại biến dạng SW tự đặt = 431×, ~10% kích thước model). Khung rất cứng.

## Diễn giải (QUAN TRỌNG)
- Đỉnh von Mises (224→350 MPa) **PHÂN KỲ theo lưới** (thô 224, mịn 350) → đây là **SINGULARITY SỐ** tại mặt đặt tải tập trung (đúng như ghi chú phương pháp FEA của đồ án trong CLAUDE.md/`KETQUA_BEN.md`), **KHÔNG phải ứng suất kết cấu thực**. Không dùng làm FOS.
- Chỉ số `disp = 598 mm` và `nodes = 0` do driver đọc ra là **ARTIFACT** (mâu thuẫn với hệ số phóng đại 431× của chính SW → disp thực ~0,6 mm; nhiều khả năng 1 node lỗi ở vùng hủ 3 nan đặc chồng nhau).
- **Kết luận kết cấu:** khung thép hộp 100×100×5 (4 cột cao 2,55 m ngàm chân, hộp kín trên–dưới) mang tải robot 2060 N → **ứng suất thân thấp (xanh), võng < 1 mm → DƯ BỀN rõ ràng**.

## Việc nên làm để có FOS "sạch" (nếu thầy yêu cầu con số chính xác)
1. Làm sạch hình học HỦ (3 nan đặc chồng + khoét Ø150 có thể tạo sliver) hoặc làm nan RỖNG.
2. Đặt tải phân bố (remote load / áp lực trên toàn đĩa) để bỏ singularity điểm.
3. Bo góc mặt đặt tải, đọc ứng suất thân (cột/vành) thay vì đỉnh singularity.

**Bằng chứng:** `figs/fea_khungtreo_final_vonMises.png` (12 mm), `figs/fea_khungtreo_vonMises.bmp` (6 mm), `out/khungtreo_final_results.csv`.

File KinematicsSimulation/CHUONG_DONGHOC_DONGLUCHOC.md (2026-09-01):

# CHƯƠNG: ĐỘNG HỌC VÀ ĐỘNG LỰC HỌC DELTA ROBOT

> Chương này trình bày hoàn chỉnh phần **động học** (thuận, nghịch, Jacobian, kỳ dị, vùng làm việc,
> giới hạn góc) và **động lực học** (phân tích lực, momen khớp) của robot delta HCMUTE, kèm dẫn công
> thức, tính toán số cụ thể và kết quả mô phỏng. Mọi con số được tính/kiểm chứng bằng MATLAB R2025a
> (`KinematicsSimulation/`, `ForceAnalysis/`).

**Thông số hình học:** R = 347 mm; r = 120,6 mm; R−r = 226,4 mm; L1 = 407,5 mm; L2 = 1000 mm;
phương vị 3 cánh tay φ = [−90°; 30°; 150°]; giới hạn góc khớp θ ∈ [−45°; 100°]; tải trọng payload 2 kg.

---

# A. ĐỘNG HỌC

## 1. Mô hình hình học và hệ tọa độ

Robot delta gồm **đế cố định** mang 3 động cơ và **bàn máy động** nối với đế qua 3 cánh tay giống nhau
cách nhau 120°. Nhờ cấu trúc cẳng tay hình bình hành, bàn máy **luôn song song với đế** — robot có 3 bậc
tự do **tịnh tiến** (x, y, z). Gốc tọa độ tại tâm mặt vai, trục z hướng xuống.

Mỗi cánh tay i: **khớp đế** Bᵢ (trục động cơ), **bắp tay** L1 quay góc θᵢ tới **khuỷu** Eᵢ, **cẳng tay**
L2 (thanh truyền, khớp cầu 2 đầu) nối tới **khớp bàn máy** Pᵢ.

$$\mathbf{B}_i = R\,[\cos\varphi_i,\ \sin\varphi_i,\ 0]^\mathsf{T} \quad (1)$$
$$\mathbf{E}_i = \mathbf{B}_i + L_1\,[\cos\theta_i\cos\varphi_i,\ \cos\theta_i\sin\varphi_i,\ -\sin\theta_i]^\mathsf{T} \quad (2)$$
$$\mathbf{P}_i = \mathbf{P} + r\,[\cos\varphi_i,\ \sin\varphi_i,\ 0]^\mathsf{T} \quad (3)$$
$$\lVert \mathbf{E}_i - \mathbf{P}_i \rVert = L_2 \qquad (i = 1,2,3) \quad (4)$$

| Khớp đế | φᵢ | Bᵢ = (x, y, z) mm |
|---|---|---|
| B₁ | −90° | (0; −347,0; 0) |
| B₂ | 30° | (300,5; 173,5; 0) |
| B₃ | 150° | (−300,5; 173,5; 0) |

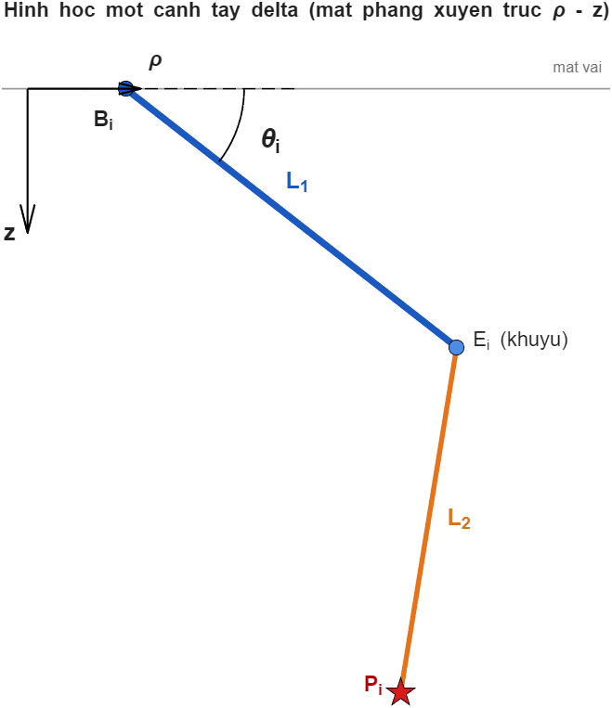
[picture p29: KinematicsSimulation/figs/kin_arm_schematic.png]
Hình 1. Hình học một cánh tay delta trong mặt phẳng xuyên trục ρ–z


## 2. Động học nghịch (P → θ): dẫn công thức

Ba cánh tay độc lập, giải riêng từng cánh tay. Chiếu P lên phương kính và phương tiếp của cánh tay i:
$$u_i = x\cos\varphi_i + y\sin\varphi_i - (R-r),\qquad w_i = -x\sin\varphi_i + y\cos\varphi_i \quad (5)$$

Thay vào ràng buộc (4) và khai triển (dùng cos²+sin²=1) đưa về **phương trình lượng giác chuẩn**:
$$E_i\sin\theta_i + F_i\cos\theta_i + G_i = 0 \quad (6)$$
$$E_i = 2L_1 z,\qquad F_i = -2L_1 u_i,\qquad G_i = L_1^2 + u_i^2 + w_i^2 + z^2 - L_2^2 \quad (7)$$

Giải bằng công thức đóng với ρᵢ = √(Eᵢ²+Fᵢ²), ψᵢ = atan2(Fᵢ,Eᵢ):
$$\theta_i = \arcsin\left(\frac{-G_i}{\rho_i}\right) - \psi_i,\qquad \text{điều kiện với tới: } \lvert G_i\rvert \le \rho_i \quad (8)$$

Phương trình (6) có hai nghiệm (hai cấu hình khuỷu); chọn nghiệm trong [−45°; 100°], lấy góc nhỏ hơn
(cấu hình phù hợp robot treo trần). Thuật toán trong `delta_ik.m`.
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

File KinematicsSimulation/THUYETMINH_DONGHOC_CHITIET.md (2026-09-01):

# THUYẾT MINH CHI TIẾT — ĐỘNG HỌC DELTA ROBOT (THUẬN & NGHỊCH)

> Tài liệu trình bày đầy đủ cơ sở lý thuyết và **cách dẫn công thức** động học nghịch (inverse
> kinematics) và động học thuận (forward kinematics) của robot delta 3 bậc tự do tịnh tiến, kèm ví dụ
> tính số và kiểm chứng. Mục tiêu: người đọc hiểu rõ *từ mô hình hình học đến công thức và lời giải*.
>
> **Công cụ:** MATLAB R2025a (`KinematicsSimulation/`: `delta_ik.m`, `delta_fk.m`, `delta_jacobian.m`).
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

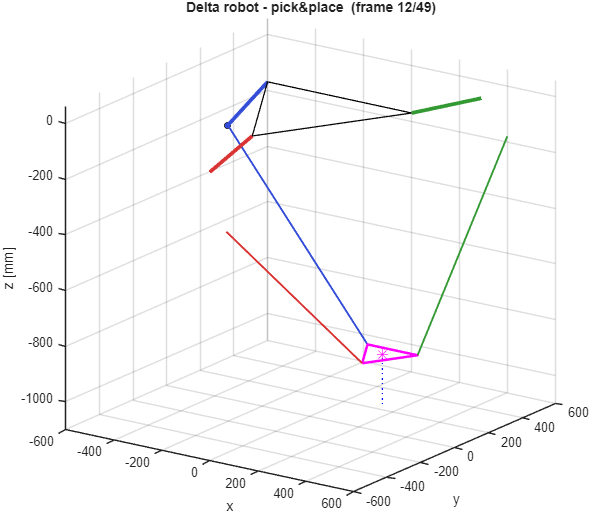
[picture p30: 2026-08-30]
KinematicsSimulation/figs/frames/fr_012.png

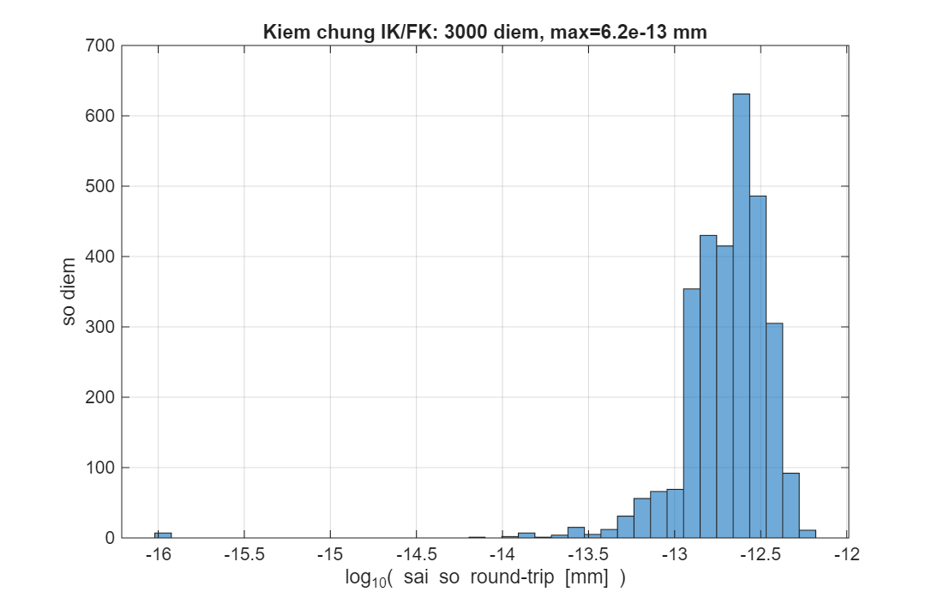
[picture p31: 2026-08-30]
KinematicsSimulation/figs/p2_roundtrip_hist.png

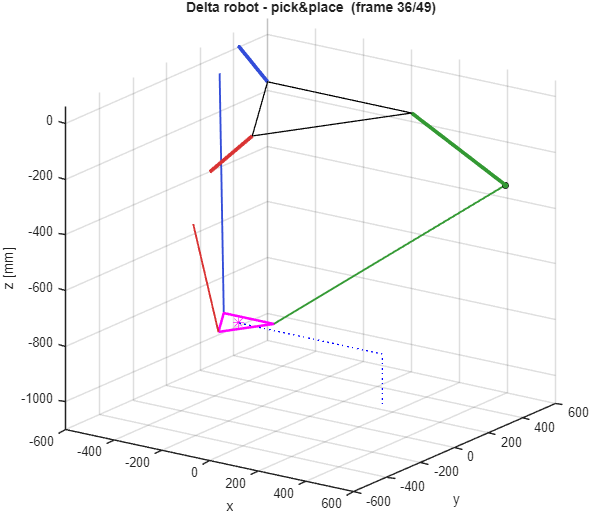
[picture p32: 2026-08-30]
KinematicsSimulation/figs/frames/fr_036.png

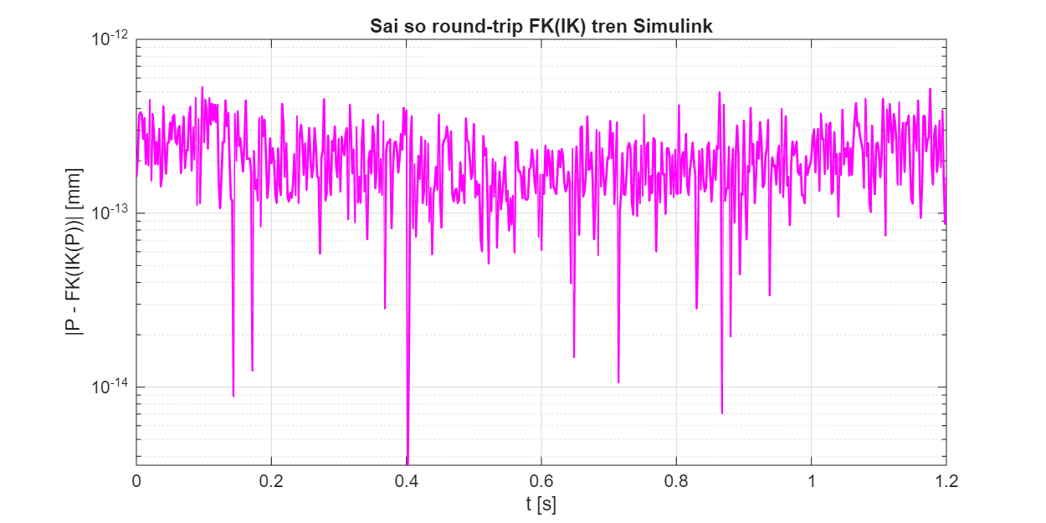
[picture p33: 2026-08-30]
KinematicsSimulation/figs/simulink_fkik_error.png

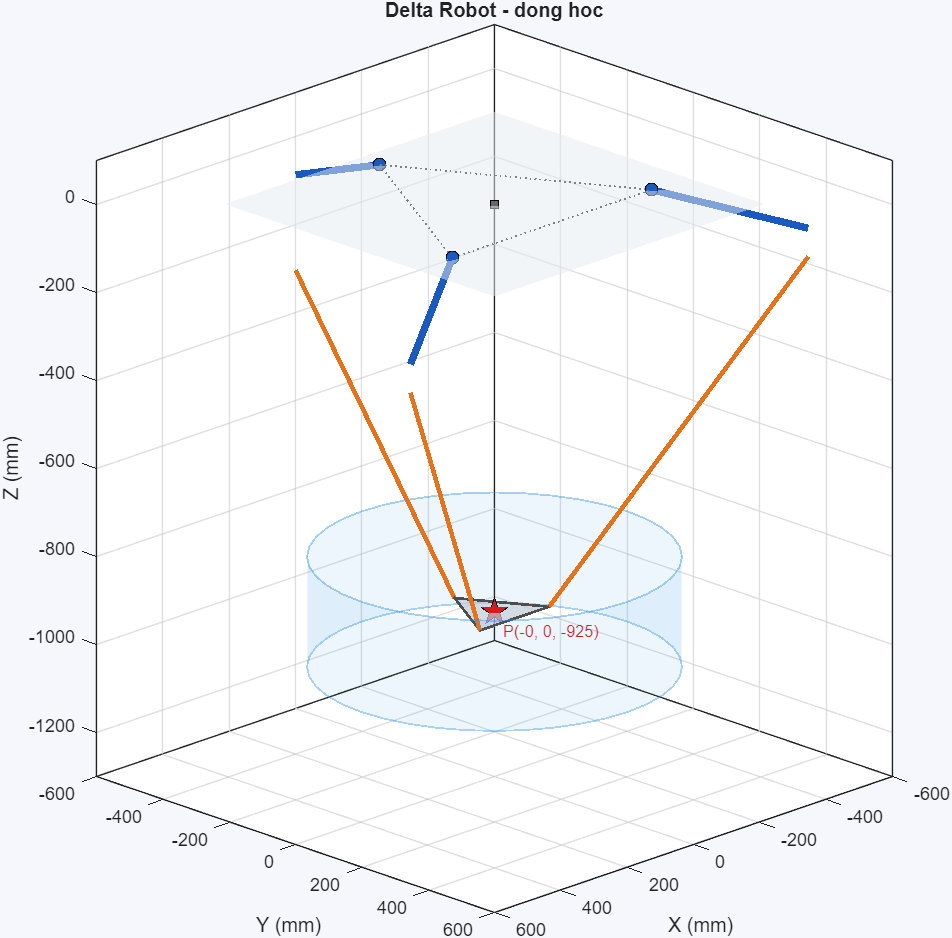
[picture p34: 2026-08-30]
KinematicsSimulation/figs/gui_simple_ws.png

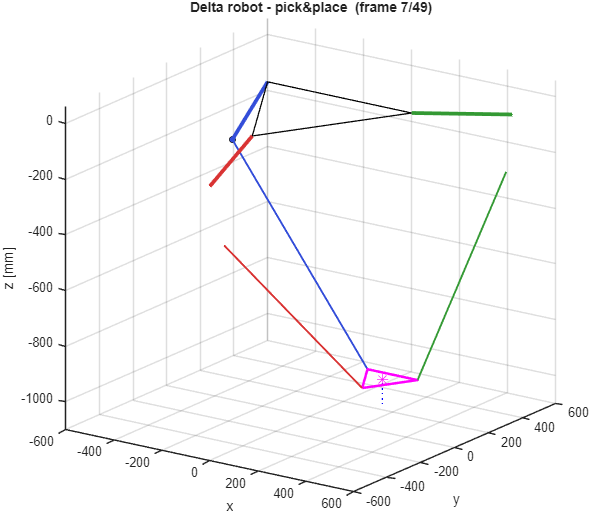
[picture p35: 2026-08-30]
KinematicsSimulation/figs/frames/fr_007.png

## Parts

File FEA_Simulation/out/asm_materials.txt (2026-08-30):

SC0 '60645K471_Ball Joint Linkage-1' bodies=3 [SolidBody 1(Chamfer1):Alloy Steel] [SolidBody 2(Fillet1):Alloy Steel] [SolidBody 3(Revolve6):Alloy Steel]
SC1 '60645K471_Ball Joint Linkage-10' bodies=3 [SolidBody 1(Chamfer1):Alloy Steel] [SolidBody 2(Fillet1):Alloy Steel] [SolidBody 3(Revolve6):Alloy Steel]
SC2 '60645K471_Ball Joint Linkage-11' bodies=3 [SolidBody 1(Chamfer1):Alloy Steel] [SolidBody 2(Fillet1):Alloy Steel] [SolidBody 3(Revolve6):Alloy Steel]
SC3 '60645K471_Ball Joint Linkage-12' bodies=3 [SolidBody 1(Chamfer1):Alloy Steel] [SolidBody 2(Fillet1):Alloy Steel] [SolidBody 3(Revolve6):Alloy Steel]
SC4 '60645K471_Ball Joint Linkage-13' bodies=3 [SolidBody 1(Chamfer1):Alloy Steel] [SolidBody 2(Fillet1):Alloy Steel] [SolidBody 3(Revolve6):Alloy Steel]
SC5 '60645K471_Ball Joint Linkage-14' bodies=3 [SolidBody 1(Chamfer1):Alloy Steel] [SolidBody 2(Fillet1):Alloy Steel] [SolidBody 3(Revolve6):Alloy Steel]
SC6 '60645K471_Ball Joint Linkage-15' bodies=3 [SolidBody 1(Chamfer1):Alloy Steel] [SolidBody 2(Fillet1):Alloy Steel] [SolidBody 3(Revolve6):Alloy Steel]
SC7 '60645K471_Ball Joint Linkage-16' bodies=3 [SolidBody 1(Chamfer1):Alloy Steel] [SolidBody 2(Fillet1):Alloy Steel] [SolidBody 3(Revolve6):Alloy Steel]
SC8 '60645K471_Ball Joint Linkage-17' bodies=3 [SolidBody 1(Chamfer1):Alloy Steel] [SolidBody 2(Fillet1):Alloy Steel] [SolidBody 3(Revolve6):Alloy Steel]
SC9 '60645K471_Ball Joint Linkage-18' bodies=3 [SolidBody 1(Chamfer1):Alloy Steel] [SolidBody 2(Fillet1):Alloy Steel] [SolidBody 3(Revolve6):Alloy Steel]
SC10 '60645K471_Ball Joint Linkage-19' bodies=3 [SolidBody 1(Chamfer1):Alloy Steel] [SolidBody 2(Fillet1):Alloy Steel] [SolidBody 3(Revolve6):Alloy Steel]
SC11 '60645K471_Ball Joint Linkage-2' bodies=3 [SolidBody 1(Chamfer1):Alloy Steel] [SolidBody 2(Fillet1):Alloy Steel] [SolidBody 3(Revolve6):Alloy Steel]
SC12 '6516K305_Connecting Rod-1' bodies=1 [SolidBody 1(Boss-Extrude2):Thornel VCB-20 Carbon Cloth]
SC13 '6516K305_Connecting Rod-2' bodies=1 [SolidBody 1(Boss-Extrude2):Thornel VCB-20 Carbon Cloth]
SC14 '6516K305_Connecting Rod-3' bodies=1 [SolidBody 1(Boss-Extrude2):Thornel VCB-20 Carbon Cloth]
SC15 '6516K305_Connecting Rod-4' bodies=1 [SolidBody 1(Boss-Extrude2):Thornel VCB-20 Carbon Cloth]
SC16 '6516K305_Connecting Rod-5' bodies=1 [SolidBody 1(Boss-Extrude2):Thornel VCB-20 Carbon Cloth]
SC17 '6516K305_Connecting Rod-6' bodies=1 [SolidBody 1(Boss-Extrude2):Thornel VCB-20 Carbon Cloth]
SC18 'DR-001-1_De-Gan-Tay-5' bodies=1 [SolidBody 1(Khoi1-DeGanTay):6061-T6 (SS)]
SC19 'DR-001-2_Khung-Han-1' bodies=1 [SolidBody 1(LoRen-M12-Goc-x3):6061-T6 (SS)]
SC20 'DR-001-3_Mat-Treo-1' bodies=1 [SolidBody 1(Khoi3-MatTreo):6061-T6 (SS)]
SC21 'DR-002_Motor-Bracket-A-2' bodies=1 [SolidBody 1(LoRen-M5-x16):6061-T6 (SS)]
SC22 'DR-002_Motor-Bracket-A-3' bodies=1 [SolidBody 1(LoRen-M5-x16):6061-T6 (SS)]
SC23 'DR-002_Motor-Bracket-A-4' bodies=1 [SolidBody 1(LoRen-M5-x16):6061-T6 (SS)]
SC24 'DR-003_Motor-Bracket-B-5' bodies=1 [SolidBody 1(LPattern4):6061-T6 (SS)]
SC25 'DR-003_Motor-Bracket-B-6' bodies=1 [SolidBody 1(LPattern4):6061-T6 (SS)]
SC26 'DR-003_Motor-Bracket-B-7' bodies=1 [SolidBody 1(LPattern4):6061-T6 (SS)]
SC27 'DR-004_Shoulder-Bracket-1' bodies=1 [SolidBody 1(LoBac-M25-CBore-x8):6061-T6 (SS)]
SC28 'DR-004_Shoulder-Bracket-10' bodies=1 [SolidBody 1(LoBac-M25-CBore-x8):6061-T6 (SS)]
SC29 'DR-004_Shoulder-Bracket-11' bodies=1 [SolidBody 1(LoBac-M25-CBore-x8):6061-T6 (SS)]
SC30 'DR-005_Upper-Arm-1/DR-005-1_Upper-Arm-Hub-1' bodies=1 [SolidBody 1(LoRen-M25-Hub-x8):6061-T6 (SS)]
SC31 'DR-005_Upper-Arm-1/DR-005-2_Upper-Arm-Link-1' bodies=1 [SolidBody 1(Thread2):6061-T6 (SS)]
SC32 'DR-005_Upper-Arm-10/DR-005-1_Upper-Arm-Hub-1' bodies=1 [SolidBody 1(LoRen-M25-Hub-x8):6061-T6 (SS)]
SC33 'DR-005_Upper-Arm-10/DR-005-2_Upper-Arm-Link-1' bodies=1 [SolidBody 1(Thread2):6061-T6 (SS)]
SC34 'DR-005_Upper-Arm-11/DR-005-1_Upper-Arm-Hub-1' bodies=1 [SolidBody 1(LoRen-M25-Hub-x8):6061-T6 (SS)]
SC35 'DR-005_Upper-Arm-11/DR-005-2_Upper-Arm-Link-1' bodies=1 [SolidBody 1(Thread2):6061-T6 (SS)]
SC36 'DR-006_Elbow-Clevis-1' bodies=1 [SolidBody 1(Mirror6):6061-T6 (SS)]
SC37 'DR-006_Elbow-Clevis-10' bodies=1 [SolidBody 1(Mirror6):6061-T6 (SS)]
SC38 'DR-006_Elbow-Clevis-11' bodies=1 [SolidBody 1(Mirror6):6061-T6 (SS)]
SC39 'DR-007_Moving-Platform-3' bodies=1 [SolidBody 1(CirPattern1):6061-T6 (SS)]
SC40 'TPMA010S-055T-5PB1-094C-W1-000-1' bodies=8 [SolidBody 1(TPMA010S-055T-5PB1-094C-W1-000.stp<1>[1]):?] [SolidBody 2(TPMA010S-055T-5PB1-094C-W1-000.stp<1>[3]):?] [SolidBody 3(TPMA010S-055T-5PB1-094C-W1-000.stp<1>[4]):?] [SolidBody 4(TPMA010S-055T-5PB1-094C-W1-000.stp<1>[8]):?] [SolidBody 5(TPMA010S-055T-5PB1-094C-W1-000.stp<1>[7]):?] [SolidBody 6(TPMA010S-055T-5PB1-094C-W1-000.stp<1>[6]):?] [SolidBody 7(TPMA010S-055T-5PB1-094C-W1-000.stp<1>[2]):?] [SolidBody 8(TPMA010S-055T-5PB1-094C-W1-000.stp<1>[5]):?]
SC41 'TPMA010S-055T-5PB1-094C-W1-000-4' bodies=8 [SolidBody 1(TPMA010S-055T-5PB1-094C-W1-000.stp<1>[1]):?] [SolidBody 2(TPMA010S-055T-5PB1-094C-W1-000.stp<1>[3]):?] [SolidBody 3(TPMA010S-055T-5PB1-094C-W1-000.stp<1>[4]):?] [SolidBody 4(TPMA010S-055T-5PB1-094C-W1-000.stp<1>[8]):?] [SolidBody 5(TPMA010S-055T-5PB1-094C-W1-000.stp<1>[7]):?] [SolidBody 6(TPMA010S-055T-5PB1-094C-W1-000.stp<1>[6]):?] [SolidBody 7(TPMA010S-055T-5PB1-094C-W1-000.stp<1>[2]):?] [SolidBody 8(TPMA010S-055T-5PB1-094C-W1-000.stp<1>[5]):?]
SC42 'TPMA010S-055T-5PB1-094C-W1-000-5' bodies=8 [SolidBody 1(TPMA010S-055T-5PB1-094C-W1-000.stp<1>[1]):?] [SolidBody 2(TPMA010S-055T-5PB1-094C-W1-000.stp<1>[3]):?] [SolidBody 3(TPMA010S-055T-5PB1-094C-W1-000.stp<1>[4]):?] [SolidBody 4(TPMA010S-055T-5PB1-094C-W1-000.stp<1>[8]):?] [SolidBody 5(TPMA010S-055T-5PB1-094C-W1-000.stp<1>[7]):?] [SolidBody 6(TPMA010S-055T-5PB1-094C-W1-000.stp<1>[6]):?] [SolidBody 7(TPMA010S-055T-5PB1-094C-W1-000.stp<1>[2]):?] [SolidBody 8(TPMA010S-055T-5PB1-094C-W1-000.stp<1>[5]):?]

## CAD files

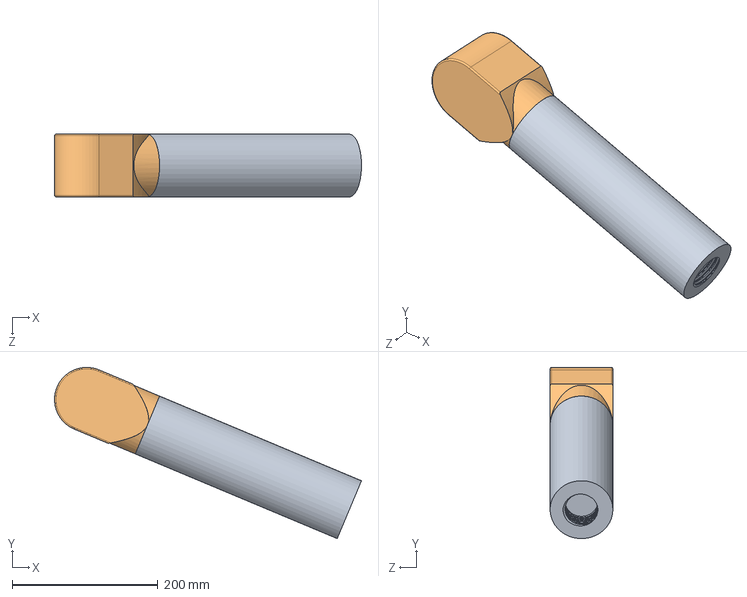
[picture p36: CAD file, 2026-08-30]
DeltaRobot_Final/DR-005_Upper-Arm.SLDASM
420.6 x 234.5 x 86.0 mm
DR-005-1_Upper-Arm-Hub
DR-005-2_Upper-Arm-Link

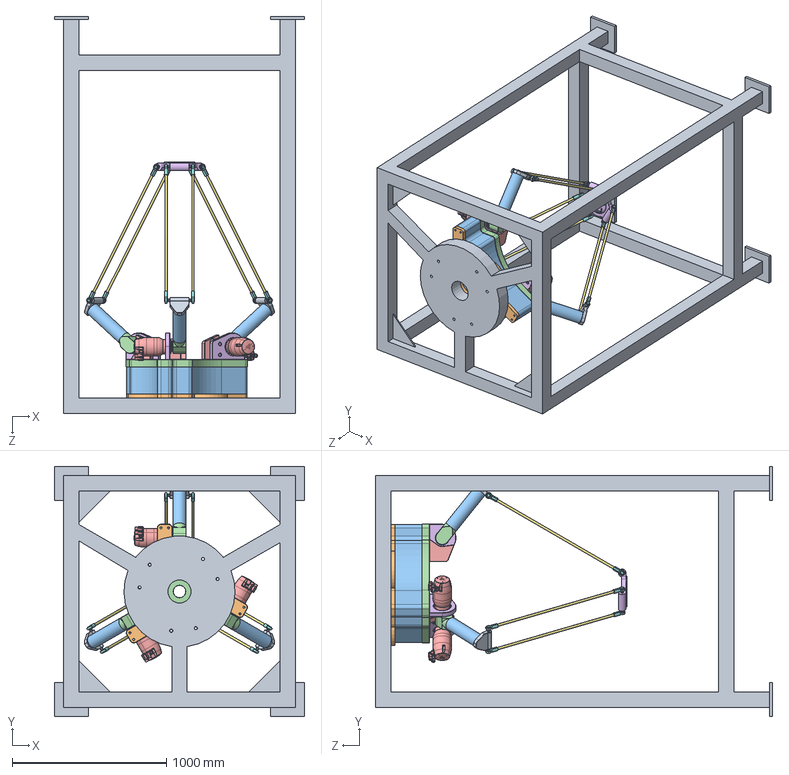
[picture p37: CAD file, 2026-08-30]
DeltaRobot_Final/DR-000_Delta-Robot_V0.SLDASM
1620.0 x 1620.0 x 2572.2 mm
DR-002_Motor-Bracket-A x 3
TPMA010S-055T-5PB1-094C-W1-000 x 3
DR-005-1_Upper-Arm-Hub x 3
DR-005-2_Upper-Arm-Link x 3
DR-004_Shoulder-Bracket x 3
DR-006_Elbow-Clevis x 3
60645K471_Ball Joint Linkage x 12
6516K305_Connecting Rod x 6
DR-007_Moving-Platform
DR-003_Motor-Bracket-B x 3
DR-001-1_De-Gan-Tay
DR-001-2_Khung-Han
DR-001-3_Mat-Treo
Frame

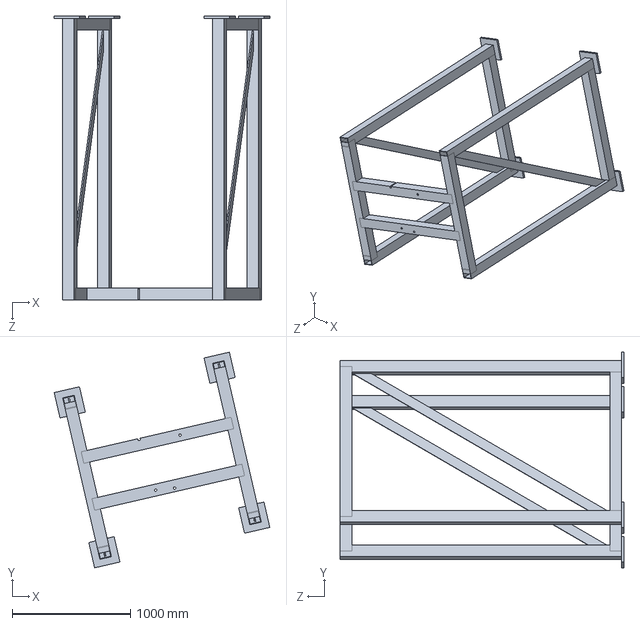
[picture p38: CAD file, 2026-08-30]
DeltaRobot_Final/DR-100_Khung-Treo.SLDPRT
1823.0 x 1823.0 x 2400.0 mm

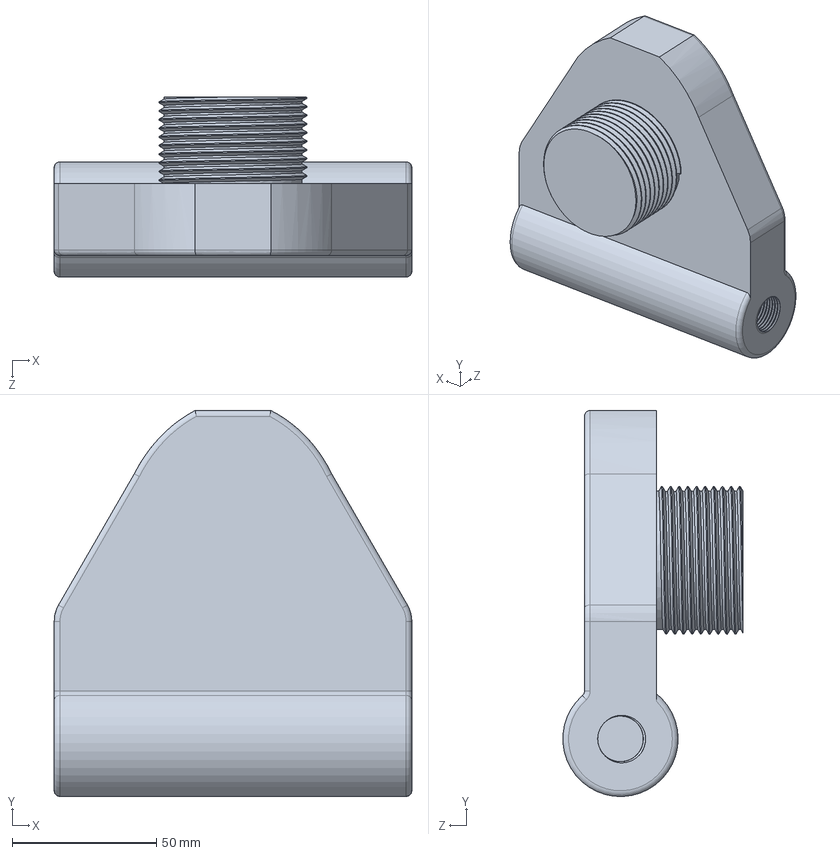
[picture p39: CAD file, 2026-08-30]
DeltaRobot_Final/DR-006_Elbow-Clevis.SLDPRT
124.0 x 133.8 x 62.4 mm

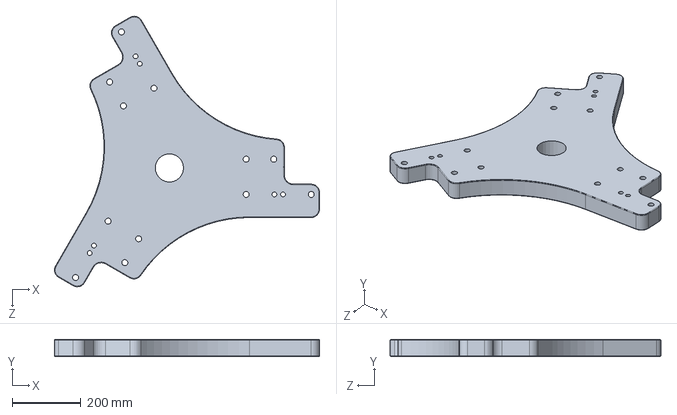
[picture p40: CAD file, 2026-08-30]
DeltaRobot_Final/DR-001-1_De-Gan-Tay.SLDPRT
769.9 x 50.0 x 786.0 mm

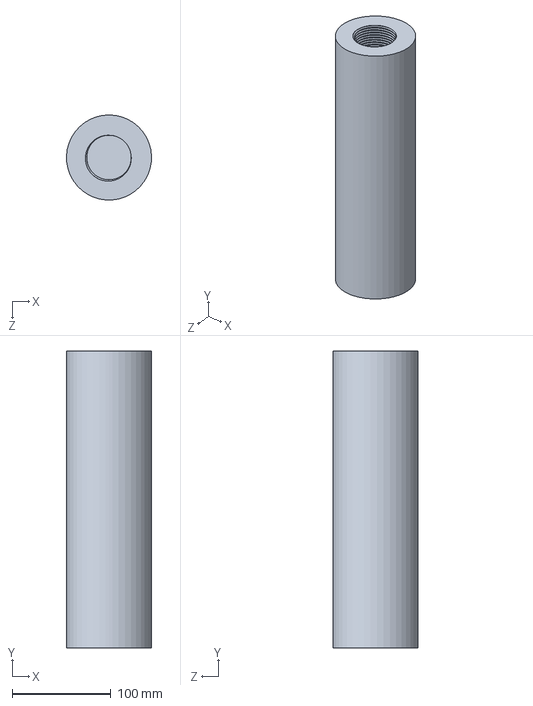
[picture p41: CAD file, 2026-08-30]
DeltaRobot_Final/DR-005-2_Upper-Arm-Link.SLDPRT
85.9 x 300.0 x 86.0 mm

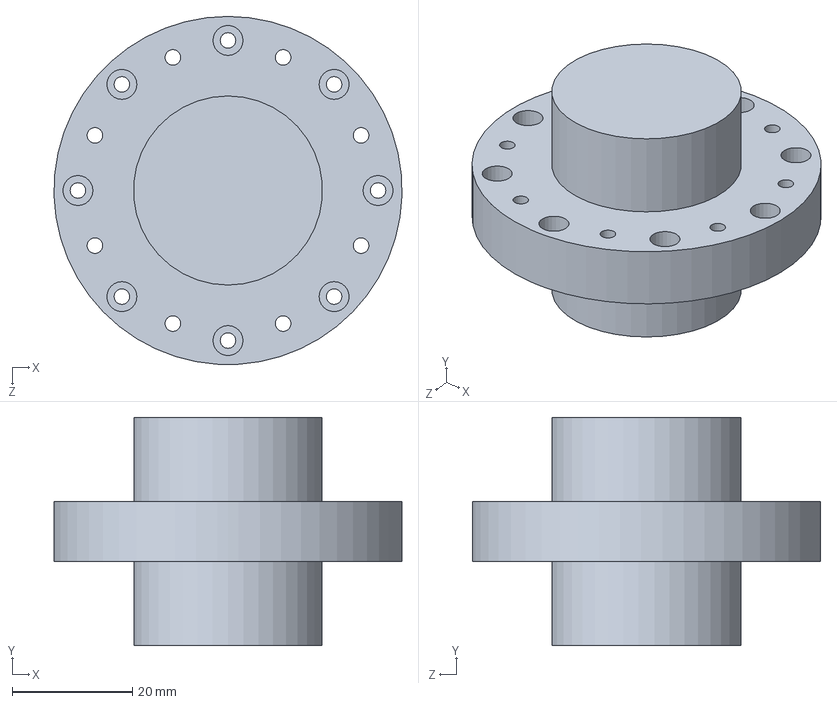
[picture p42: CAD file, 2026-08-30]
DeltaRobot_Final/DR-004_Shoulder-Bracket.SLDPRT
58.0 x 38.0 x 58.0 mm

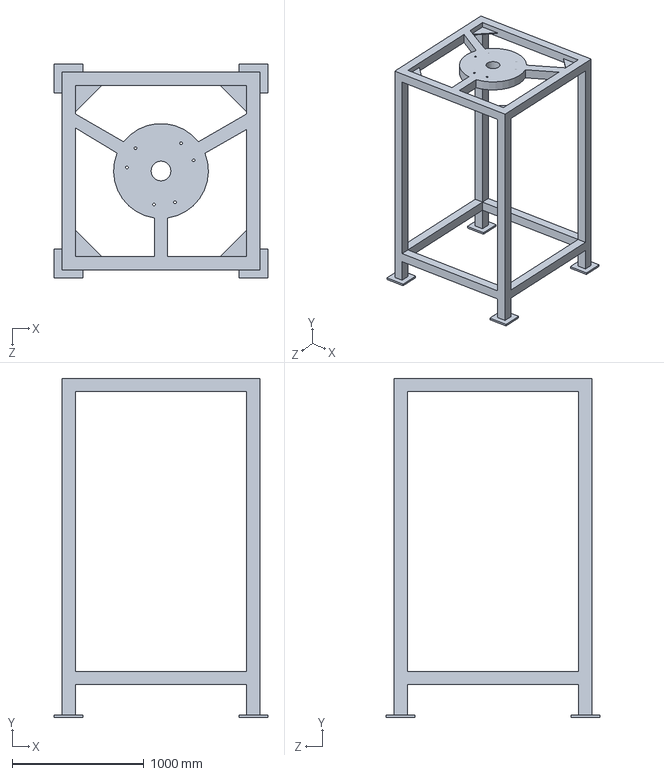
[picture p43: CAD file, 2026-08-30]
DeltaRobot_Final/Frame.SLDPRT
1620.0 x 2572.2 x 1620.0 mm

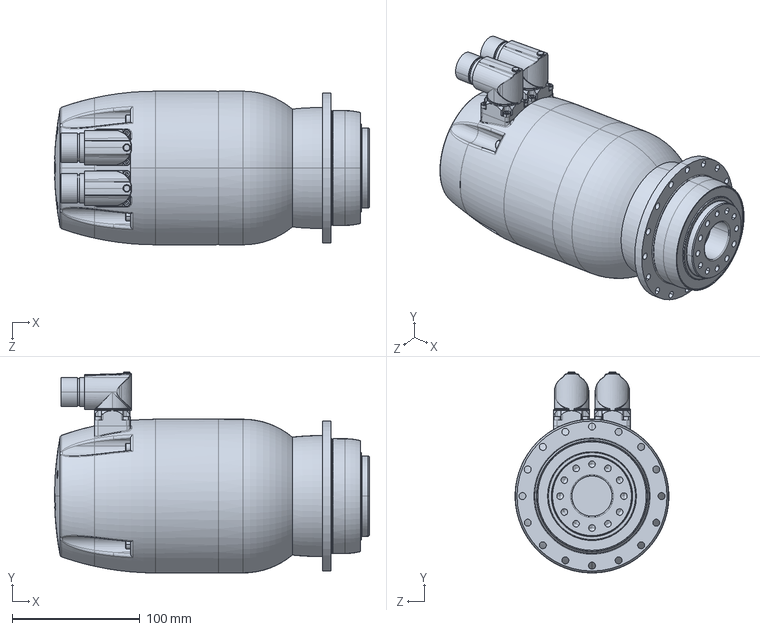
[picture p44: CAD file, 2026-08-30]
DeltaRobot_Final/TPMA010S-055T-5PB1-094C-W1-000.SLDPRT
246.8 x 157.4 x 120.4 mm

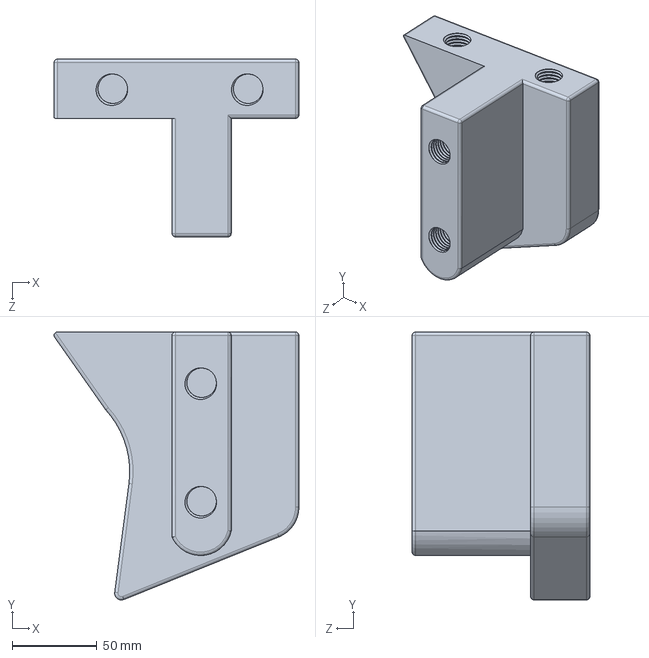
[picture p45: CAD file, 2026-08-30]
DeltaRobot_Final/DR-003_Motor-Bracket-B.SLDPRT
144.7 x 158.3 x 105.0 mm

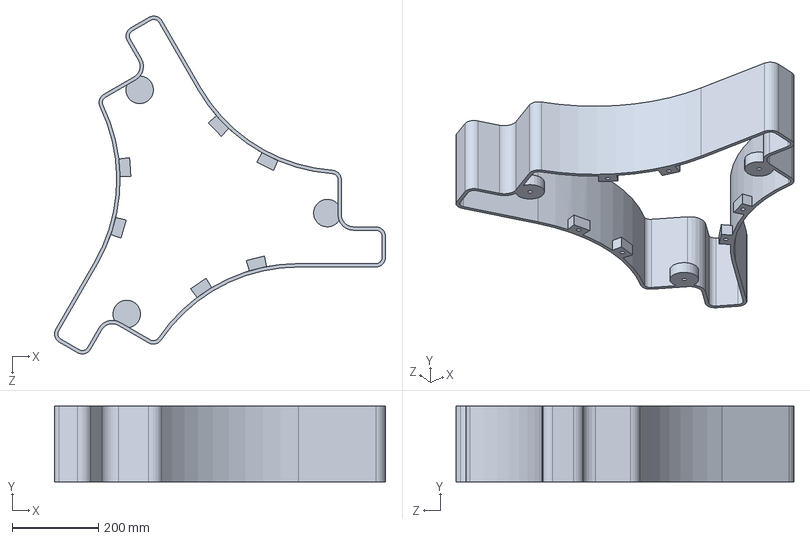
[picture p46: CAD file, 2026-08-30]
DeltaRobot_Final/DR-001-2_Khung-Han.SLDPRT
765.9 x 175.0 x 782.0 mm

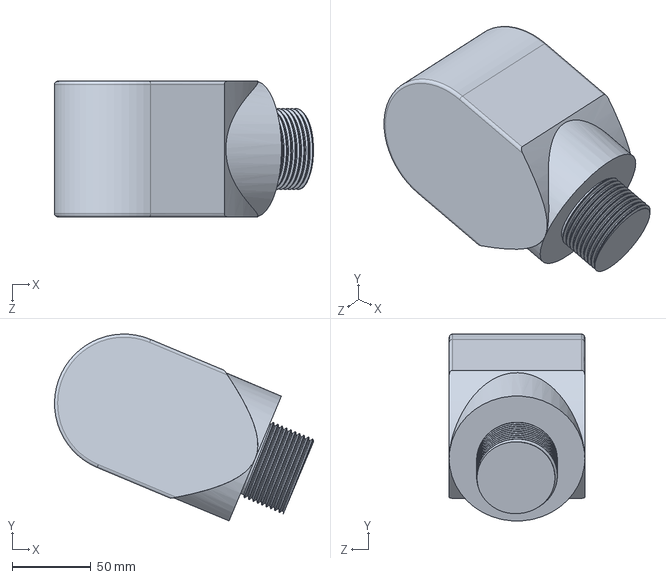
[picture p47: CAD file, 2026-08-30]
DeltaRobot_Final/DR-005-1_Upper-Arm-Hub.SLDPRT
164.2 x 118.4 x 86.0 mm

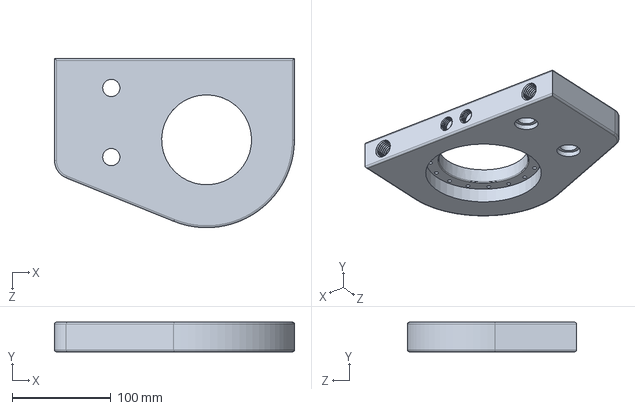
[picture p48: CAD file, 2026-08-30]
DeltaRobot_Final/DR-002_Motor-Bracket-A.SLDPRT
243.0 x 30.0 x 171.4 mm

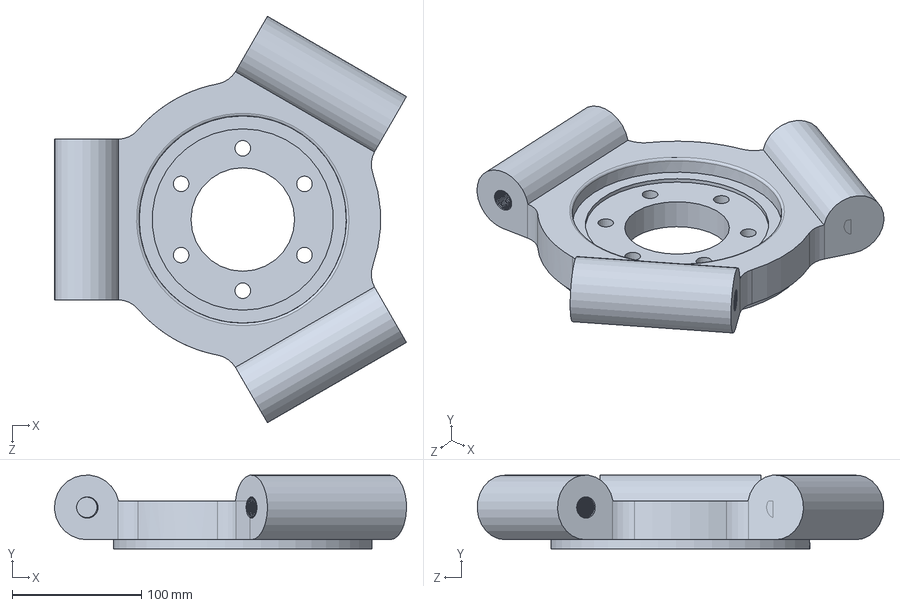
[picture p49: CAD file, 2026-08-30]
DeltaRobot_Final/DR-007_Moving-Platform.SLDPRT
271.9 x 56.8 x 313.9 mm

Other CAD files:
DeltaRobot_Final/TPM-010S-061T-5PB1-064A-W1-000.SLDPRT
DeltaRobot_Final/DR-001-3_Mat-Treo.SLDPRT
DeltaRobot_Final/60645K471_Ball Joint Linkage.SLDPRT
DeltaRobot_Final/6516K305_Connecting Rod.SLDPRT
MachiningDrawings/BanVe_ChinhSua_V7/DR-001-1_De-Gan-Tay.SLDDRW
MachiningDrawings/BanVe_ChinhSua_V7/DR-001-2_Khung-Han.SLDDRW
MachiningDrawings/BanVe_ChinhSua_V7/DR-001-3_Mat-Treo.SLDDRW
MachiningDrawings/BanVe_ChinhSua_V7/DR-002_Motor-Bracket-A.SLDDRW
MachiningDrawings/BanVe_ChinhSua_V7/DR-003_Motor-Bracket-B.SLDDRW
MachiningDrawings/BanVe_ChinhSua_V7/DR-004_Shoulder-Bracket.SLDDRW
MachiningDrawings/BanVe_ChinhSua_V7/DR-005-1_Upper-Arm-Hub.SLDDRW
MachiningDrawings/BanVe_ChinhSua_V7/DR-005-2_Upper-Arm-Link.SLDDRW
MachiningDrawings/BanVe_ChinhSua_V7/DR-006_Elbow-Clevis.SLDDRW
MachiningDrawings/BanVe_ChinhSua_V7/DR-007_Moving-Platform.SLDDRW

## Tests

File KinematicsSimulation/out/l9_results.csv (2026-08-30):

Run | L1 | L2 | R | r | Volume_mm3 | MaxCrossSectionArea_mm2 | MaxCrossSectionZ_mm | GateCornersReachable(0-4)
0 | 407.50 | 1000.00 | 347.00 | 120.60 | 26984448.0 | 1241519.2 | -693.63 | 4
1 | 350.00 | 850.00 | 300.00 | 90.00 | 26775360.0 | 840923.6 | -592.34 | 2
2 | 350.00 | 1000.00 | 347.00 | 120.60 | 26986176.0 | 1181419.0 | -727.09 | 4
3 | 350.00 | 1150.00 | 394.00 | 150.00 | 27000000.0 | 1545312.3 | -859.86 | 2
4 | 407.50 | 850.00 | 347.00 | 150.00 | 26751168.0 | 906343.2 | -543.54 | 2
5 | 407.50 | 1000.00 | 394.00 | 90.00 | 26604288.0 | 952743.9 | -699.26 | 4
6 | 407.50 | 1150.00 | 300.00 | 120.60 | 27000000.0 | 2007480.3 | -787.86 | 2
7 | 465.00 | 850.00 | 394.00 | 120.60 | 24463296.0 | 655027.8 | -508.73 | 2
8 | 465.00 | 1000.00 | 300.00 | 150.00 | 27000000.0 | 1595430.1 | -628.01 | 4
9 | 465.00 | 1150.00 | 347.00 | 90.00 | 27000000.0 | 1662356.7 | -789.06 | 4

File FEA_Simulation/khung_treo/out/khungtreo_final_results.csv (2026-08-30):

elem_mm | nodes | elems | vonMises_MPa | disp_mm | FOS
6 | 0 | 0 | 350.19 | 600.3149 | 0.7
12 | 0 | 0 | 224.06 | 598.0806 | 1.1

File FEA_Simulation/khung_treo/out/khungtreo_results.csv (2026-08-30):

elem_mm | vonMises_MPa | disp_mm | FOS
6 | 4.134 | 49.7373 | 60.47

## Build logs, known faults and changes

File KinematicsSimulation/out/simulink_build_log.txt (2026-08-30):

=== BUILD SIMULINK: delta_kinematics ===
MATLAB 25.1.0.2943329 (R2025a)
Simulink: 25.1
  TrajGen  in=1 out=1 (mong doi in=1 out=1)
  IK       in=1 out=1 (mong doi in=1 out=1)
  FK       in=1 out=1 (mong doi in=1 out=1)
  Jac      in=2 out=2 (mong doi in=2 out=2)
  ErrNorm  in=1 out=1 (mong doi in=1 out=1)
Da luu figs/simulink_model.png
Da luu F:\DeltaRobot\MoPhong_DongHoc\delta_kinematics.slx

--- CHAY SIM (StopTime=1.2s, ode3, dt=0.002) ---
Sim xong: 12 buoc thoi gian, 1 kenh

--- KET QUA (doc tu SIM) ---
Khop 1: |theta|max=1000.0 deg, |omega|max=999.9 deg/s (166.65 rpm)
Khop 2: |theta|max=1000.0 deg, |omega|max=999.8 deg/s (166.64 rpm)
Khop 3: |theta|max=999.9 deg, |omega|max=999.7 deg/s (166.62 rpm)
Jacobian cond: max=300.000, tb=-44.621 ; goc truyen mu min=-999.5 deg
Sai so round-trip FK(IK(P)) max = 3.000e+02 mm
{Error using plot
Specify the coordinates as vectors or matrices of the same size, or as a vector and a matrix that share the same length in at least one dimension.

Error in build_simulink (line 124)
subplot(2,1,1); plot(t,THd,'LineWidth',1.3); grid on; ylabel('\theta [deg]');
                ^^^^^^^^^^^^^^^^^^^^^^^^^^^
} 
=== BUILD SIMULINK: delta_kinematics ===
MATLAB 25.1.0.2943329 (R2025a)
Simulink: 25.1
  TrajGen  in=1 out=1 (mong doi in=1 out=1)
  IK       in=1 out=1 (mong doi in=1 out=1)
  FK       in=1 out=1 (mong doi in=1 out=1)
  Jac      in=2 out=2 (mong doi in=2 out=2)
  ErrNorm  in=1 out=1 (mong doi in=1 out=1)
Da luu figs/simulink_model.png
Da luu F:\DeltaRobot\MoPhong_DongHoc\delta_kinematics.slx

--- CHAY SIM (StopTime=1.2s, ode3, dt=0.002) ---
{Error using build_simulink (line 101)
Log width = 1 (mong doi 12) -- Mux/To Workspace sai.
} 
=== BUILD SIMULINK: delta_kinematics ===
MATLAB 25.1.0.2943329 (R2025a)
Simulink: 25.1
  TrajGen  in=1 out=1 (mong doi in=1 out=1)
  IK       in=1 out=1 (mong doi in=1 out=1)
  FK       in=1 out=1 (mong doi in=1 out=1)
  Jac      in=2 out=2 (mong doi in=2 out=2)
  ErrNorm  in=1 out=1 (mong doi in=1 out=1)
Da luu figs/simulink_model.png
Da luu F:\DeltaRobot\MoPhong_DongHoc\delta_kinematics.slx

--- CHAY SIM (StopTime=1.2s, ode3, dt=0.002) ---
Sim xong: 601 buoc thoi gian, 12 kenh

--- KET QUA (doc tu SIM) ---
Khop 1: |theta|max=34.3 deg, |omega|max=127.4 deg/s (21.23 rpm)
Khop 2: |theta|max=53.9 deg, |omega|max=21178.7 deg/s (3529.78 rpm)
Khop 3: |theta|max=53.9 deg, |omega|max=21178.8 deg/s (3529.79 rpm)
Jacobian cond: max=2.285, tb=2.011 ; goc truyen mu min=53.8 deg
Sai so round-trip FK(IK(P)) max = 5.324e-13 mm
Da luu 5 figs + out/simulink_results.mat
=== HOAN TAT ===
=== BUILD SIMULINK: delta_kinematics ===
MATLAB 25.1.0.2943329 (R2025a)
Simulink: 25.1
  TrajGen  in=1 out=1 (mong doi in=1 out=2)
  IK       in=1 out=1 (mong doi in=1 out=1)
  FK       in=1 out=1 (mong doi in=1 out=1)
  Jac      in=2 out=2 (mong doi in=2 out=2)
  JointVel in=3 out=1 (mong doi in=3 out=1)
  ErrNorm  in=1 out=1 (mong doi in=1 out=1)
{Error using build_simulink (line 66)
Invalid Simulink object name: 'TrajGen/2'.
} 
[Warning: Unable to close the model 'delta_kinematics' because it has been changed. To save changes, use close_system('delta_kinematics',1). To discard changes, use
close_system('delta_kinematics',0).] 
=== BUILD SIMULINK: delta_kinematics ===
MATLAB 25.1.0.2943329 (R2025a)
Simulink: 25.1
  TrajGen  in=1 out=2 (mong doi in=1 out=2)
  IK       in=1 out=1 (mong doi in=1 out=1)
  FK       in=1 out=1 (mong doi in=1 out=1)
  Jac      in=2 out=2 (mong doi in=2 out=2)
  JointVel in=3 out=1 (mong doi in=3 out=1)
  ErrNorm  in=1 out=1 (mong doi in=1 out=1)
Da luu figs/simulink_model.png
Da luu F:\DeltaRobot\MoPhong_DongHoc\delta_kinematics.slx

--- CHAY SIM (StopTime=1.2s, ode3, dt=0.002) ---
Sim xong: 601 buoc thoi gian, 12 kenh

--- KET QUA (doc tu SIM) ---
Khop 1: |theta|max=34.3 deg, |omega|max=127.4 deg/s (21.23 rpm)
Khop 2: |theta|max=53.9 deg, |omega|max=180.4 deg/s (30.07 rpm)
Khop 3: |theta|max=53.9 deg, |omega|max=180.4 deg/s (30.07 rpm)
Jacobian cond: max=2.285, tb=2.011 ; goc truyen mu min=53.8 deg
Sai so round-trip FK(IK(P)) max = 5.324e-13 mm
Da luu 5 figs + out/simulink_results.mat
=== HOAN TAT ===

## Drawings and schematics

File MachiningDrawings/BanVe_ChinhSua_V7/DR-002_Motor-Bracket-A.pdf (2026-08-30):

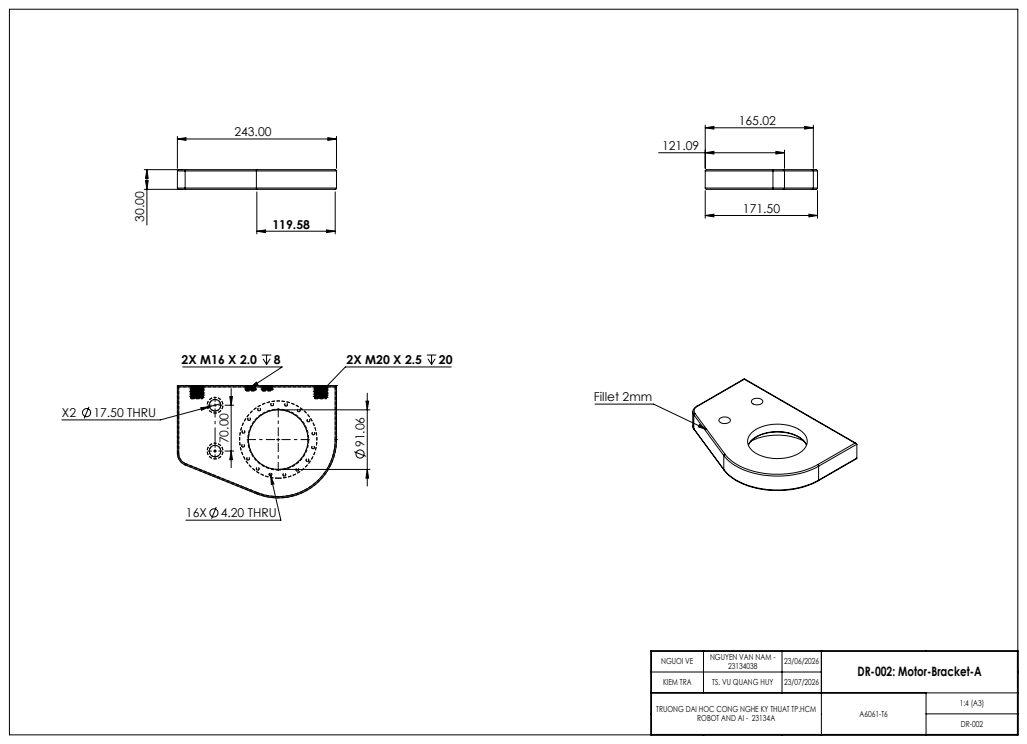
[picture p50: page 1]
X2 17.50 THRU; 16X 4.20 THRU; Fillet 2mm

NGUOI VE | NGUYEN VAN NAM -23134038 | 23/06/2026 | DR-002: Motor-Bracket-A

KIEM TRA | TS. VU QUANG HUY | 23/07/2026
TRUONG DAI HOC CONG NGHE KY THUAT TP.HCM ROBOT AND AI - 23134A | A6061-T6 | 1:4 (A3)

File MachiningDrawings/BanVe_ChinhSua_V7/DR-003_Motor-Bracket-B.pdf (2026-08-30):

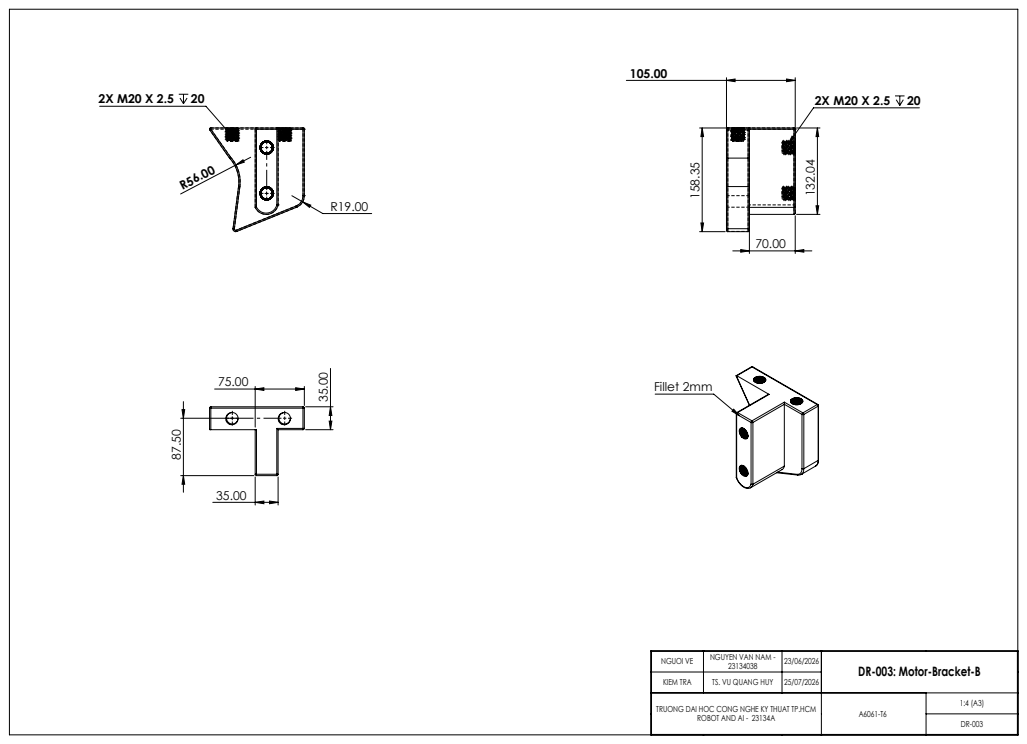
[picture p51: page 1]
Fillet 2mm

NGUOI VE | NGUYEN VAN NAM -23134038 | 23/06/2026 | DR-003: Motor-Bracket-B

KIEM TRA | TS. VU QUANG HUY | 25/07/2026
TRUONG DAI HOC CONG NGHE KY THUAT TP.HCM ROBOT AND AI - 23134A | A6061-T6 | 1:4 (A3)

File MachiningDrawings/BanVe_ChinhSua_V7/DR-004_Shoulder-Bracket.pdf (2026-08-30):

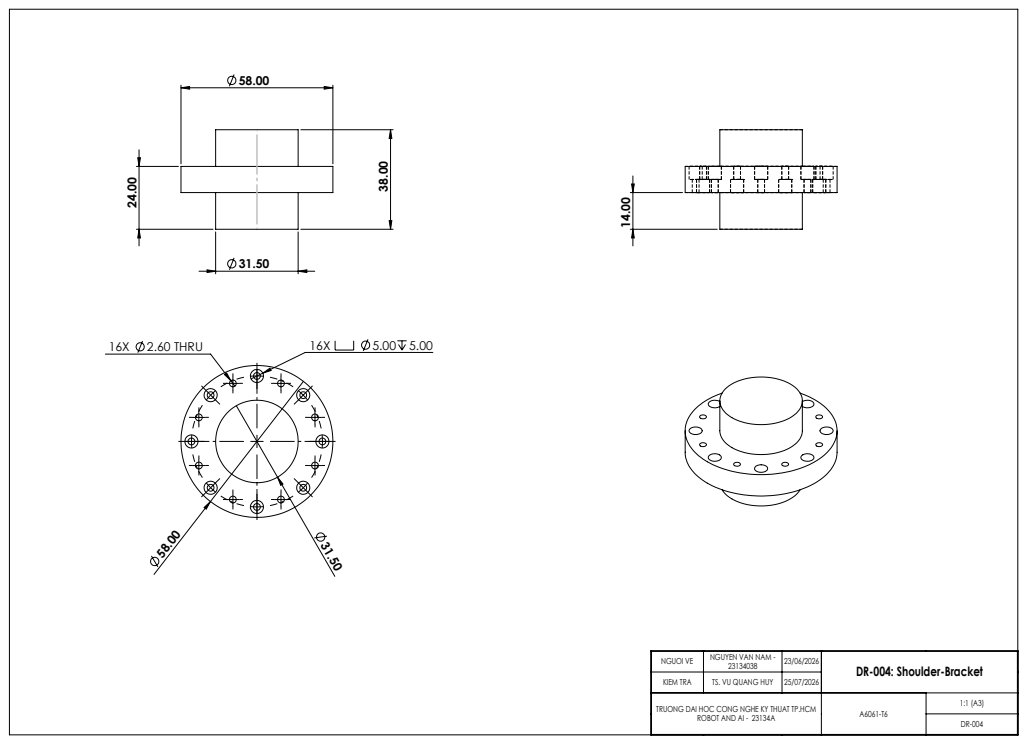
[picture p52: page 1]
16X 2.60 THRU

NGUOI VE | NGUYEN VAN NAM -23134038 | 23/06/2026 | DR-004: Shoulder-Bracket

KIEM TRA | TS. VU QUANG HUY | 25/07/2026
TRUONG DAI HOC CONG NGHE KY THUAT TP.HCM ROBOT AND AI - 23134A | A6061-T6 | 1:1 (A3)

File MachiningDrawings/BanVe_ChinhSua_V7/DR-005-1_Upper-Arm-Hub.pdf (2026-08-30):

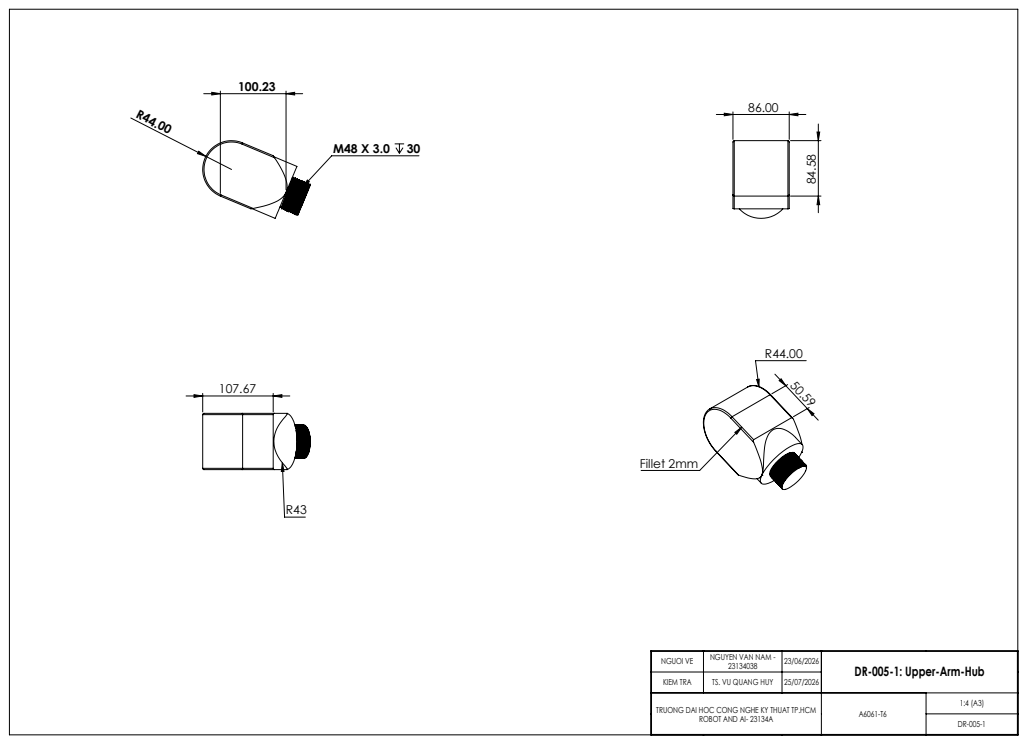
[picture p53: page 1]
Fillet 2mm

NGUOI VE | NGUYEN VAN NAM -23134038 | 23/06/2026 | DR-005-1: Upper-Arm-Hub

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

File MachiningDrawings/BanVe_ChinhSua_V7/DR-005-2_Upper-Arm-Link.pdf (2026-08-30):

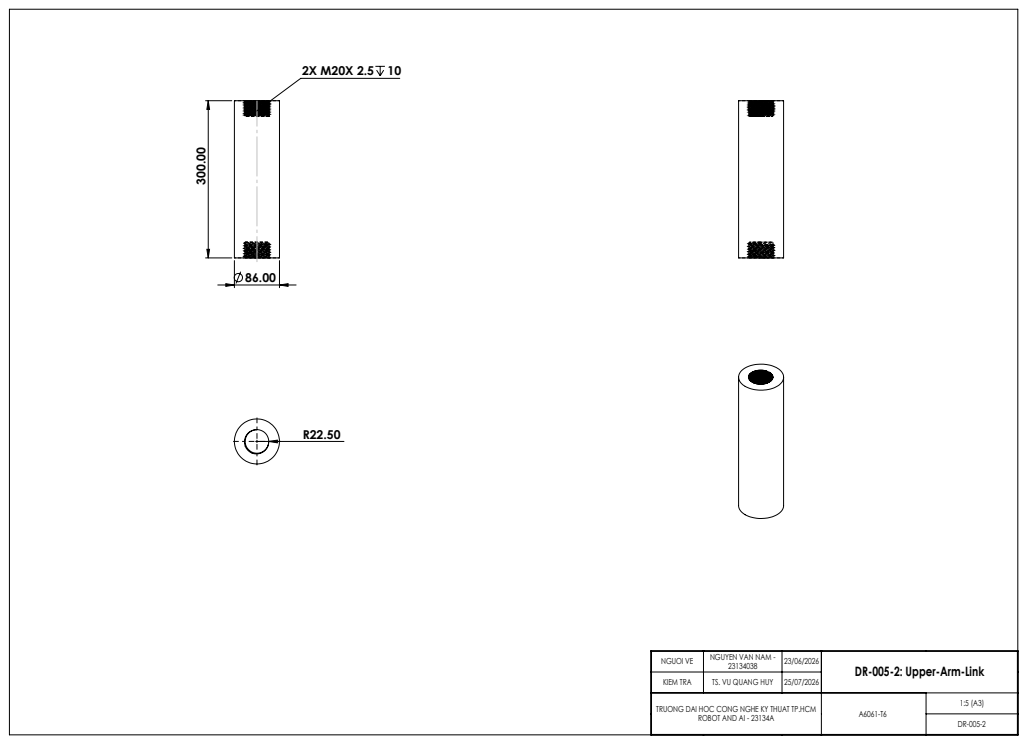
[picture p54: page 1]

NGUOI VE | NGUYEN VAN NAM -23134038 | 23/06/2026 | DR-005-2: Upper-Arm-Link

KIEM TRA | TS. VU QUANG HUY | 25/07/2026
TRUONG DAI HOC CONG NGHE KY THUAT TP.HCM ROBOT AND AI - 23134A | A6061-T6 | 1:5 (A3)

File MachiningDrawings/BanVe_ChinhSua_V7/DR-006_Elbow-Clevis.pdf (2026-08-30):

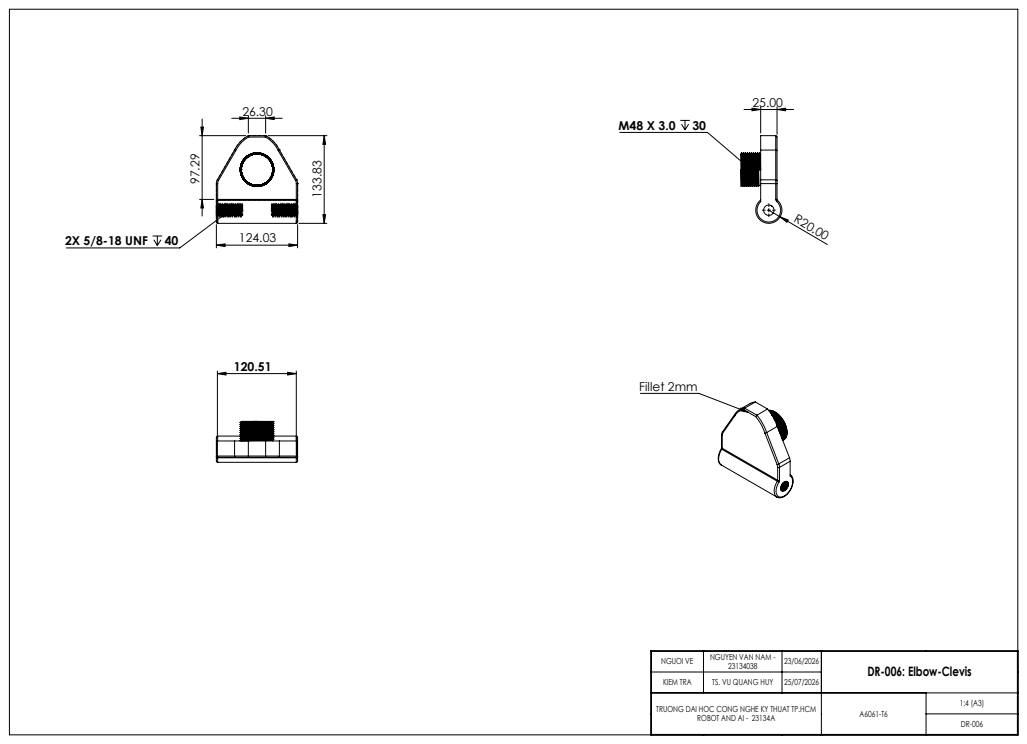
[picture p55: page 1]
2X 5/8-18 UNF 40; Fillet 2mm

NGUOI VE | NGUYEN VAN NAM -23134038 | 23/06/2026 | DR-006: Elbow-Clevis

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

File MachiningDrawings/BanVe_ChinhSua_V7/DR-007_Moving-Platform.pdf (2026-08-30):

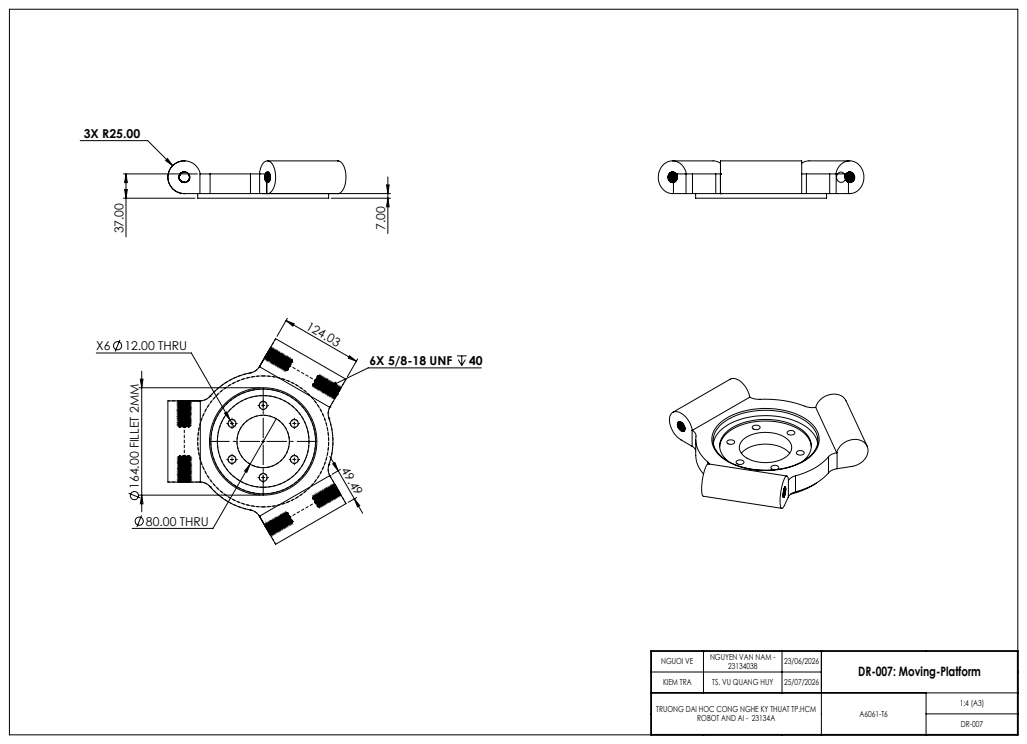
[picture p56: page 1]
80.00 THRU; 164.00 FILLET 2MM; X6 12.00 THRU; 6X 5/8-18 UNF 40

NGUOI VE | NGUYEN VAN NAM -23134038 | 23/06/2026 | DR-007: Moving-Platform

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

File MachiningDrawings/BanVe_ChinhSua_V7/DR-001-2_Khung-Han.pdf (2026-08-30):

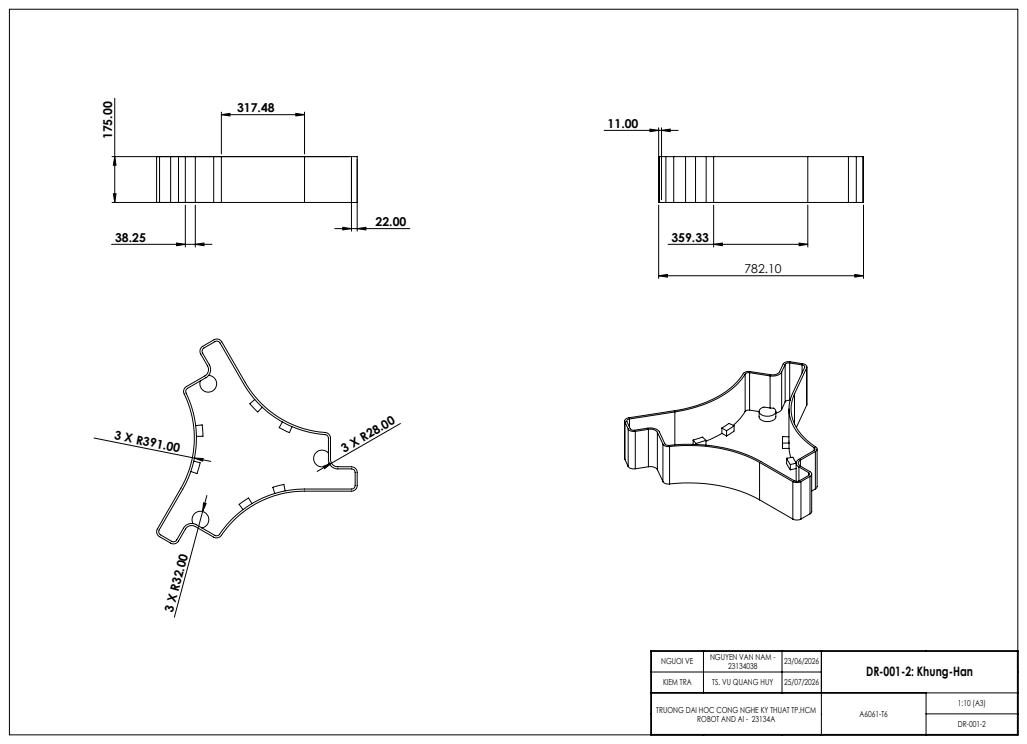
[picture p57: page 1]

NGUOI VE | NGUYEN VAN NAM -23134038 | 23/06/2026 | DR-001-2: Khung-Han

KIEM TRA | TS. VU QUANG HUY | 25/07/2026
TRUONG DAI HOC CONG NGHE KY THUAT TP.HCM ROBOT AND AI - 23134A | A6061-T6 | 1:10 (A3)

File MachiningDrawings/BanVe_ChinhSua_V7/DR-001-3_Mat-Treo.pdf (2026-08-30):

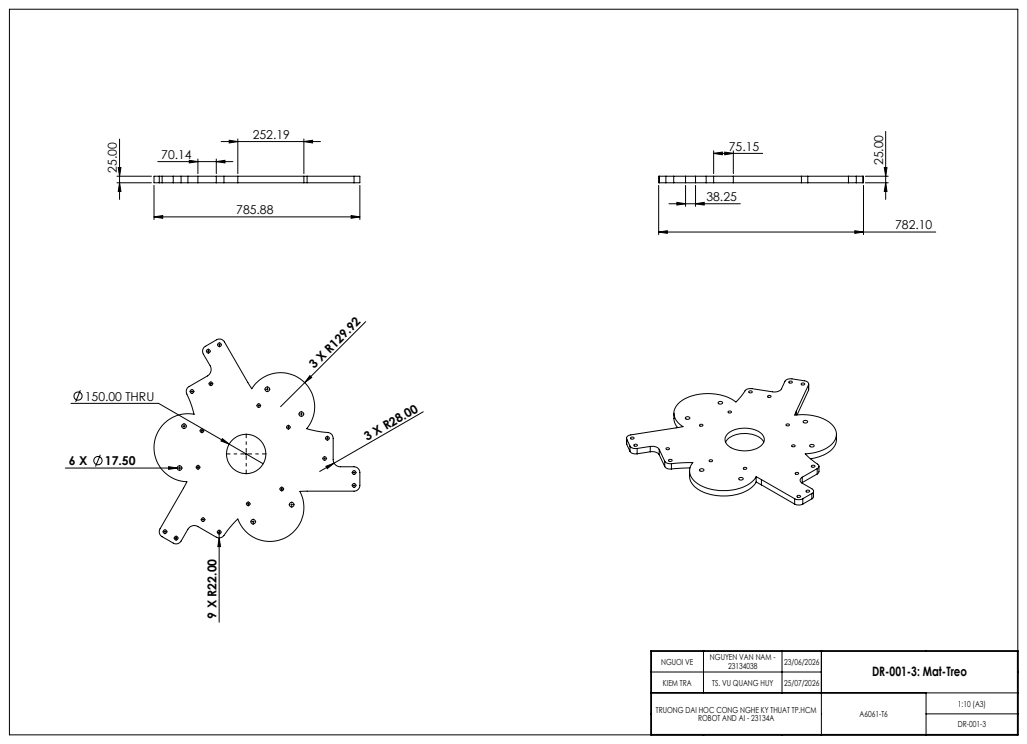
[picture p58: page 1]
150.00 THRU

NGUOI VE | NGUYEN VAN NAM -23134038 | 23/06/2026 | DR-001-3: Mat-Treo

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

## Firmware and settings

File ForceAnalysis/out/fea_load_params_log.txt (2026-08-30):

=== TONG HOP THONG SO TAI TRONG FEA -- DELTA ROBOT (payload 2 kg) ===

--- Du lieu doc lai (KHONG tinh lai) ---
 out/force_results.mat: fMax = 122.7252 N , FeeMax = 175.8165 N , L1m = 0.4075 m
 out/pose_results.mat : fw   = 182.4498 N , Fw     = 176.1039 N , tw = 74.2858 N.m , L1m = 0.4075 m
 Ty le worst-case/baseline r_pose = fw/fMax = 1.4867 (1.49x)

--- 1. DR-006 Elbow-Clevis (baseline) ---
 Co che: 1 cap forearm (2 thanh) bat vao 2 lo rod tren chac khuyu.
 Cong thuc: F = fMax/2 = 122.73/2 = 61.36 N
 Doi chieu run_parts.ps1 dong 17 (Comp=61.35 N): KHOP

--- 1b. DR-006 (pose worst-case, x1.49) ---
 Cong thuc: F = fw/2 = 182.45/2 = 91.22 N
 Doi chieu run_parts_pose.ps1 dong 10 (Comp=91.20 N): KHOP

--- 2. DR-005-2 Upper-Arm-Link (baseline) ---
 Co che: momen uon bicep Mbicep=fMax*L1m quy ve luc ngang dat dau
         khuyu, ngam dau vai, canh tay don = khoang cach 2 bore = 270 mm.
 Cong thuc: Mbicep = fMax*L1m = 122.73*0.4075 = 50.01 N.m
            F = Mbicep/L_arm52 = 50.01/0.270 = 185.22 N
 Doi chieu run_parts.ps1 dong 18 (Comp=185.00 N): KHOP
 Ghi chu: L_arm52=270mm la SUY DIEN cua phien nay tu 2 nguon doc lap
          (toa do mat trong run_parts.ps1 va cong thuc dam trong
          THUYETMINH muc 8) -- KHONG co 1 dong cong thuc F=M/L tuong
          minh nao trong tai lieu goc, nhung khop voi 185N hardcode
          trong pham vi lam tron (185.22 vs 185).

--- 2b. DR-005-2 (pose worst-case) ---
 Cong thuc: Mbicep_pose = fw*L1m = 182.45*0.4075 = 74.35 N.m (~= tw doc tu pose_results.mat = 74.29 N.m)
            F = Mbicep_pose/L_arm52 = 74.35/0.270 = 275.36 N
 Doi chieu run_parts_pose.ps1 dong 12 (Comp=275.00 N): KHOP

--- 3. DR-007 Moving-Platform (baseline) ---
 Co che: FeeMax dat tai tam ban may, chia deu 6 lo bat tool.
 Cong thuc: F = FeeMax/6 = 175.82/6 = 29.30 N
 Doi chieu run_parts.ps1 dong 19 (Comp=29.30 N): KHOP

Ghi chu: DR-007 KHONG co phien ban pose worst-case trong run_parts_pose.ps1
  (xem run_parts_pose.ps1 dong 2-3: "Platform Fee 176.1N ~ unchanged (pose-
  independent) so DR-007 skipped" -- Fw doc tu pose_results.mat = 176.10 N, gan
  bang FeeMax baseline 175.82 N, khop voi ly do bo qua nay).

--- 4. 6516K305 Rod (connecting rod, baseline) ---
 Co che: luc doc truc 1 thanh trong 1 cap (nen/keo) = fMax/2.
 Cong thuc: F = fMax/2 = 122.73/2 = 61.36 N
 Doi chieu run_parts.ps1: KHONG CO -- rod la chi tiet MUA (6516K305),
   khong nam trong danh sach 5 part cua run_parts.ps1/run_parts_pose.ps1.
 KIEM TRA EULER BUCKLING: force_analysis.m dong ~219 CHI IN RA dong chu
   "kiem oan Euler" nhu MOT GHI CHU/VIEC-CAN-LAM, KHONG co cong thuc/so
   lieu Euler (P_cr, do manh...) nao duoc TINH trong file do. => CHUA XAC
   MINH DUOC so lieu kiem Euler; KHONG bia cong thuc moi o day (tranh tinh
   lai vat ly ngoai pham vi "doc lai .mat" cua nhiem vu nay).

--- 5. DR-001-1 De-Gan-Tay (tam de, ket cau tinh) ---
 Nguon: KETQUA_BEN.md dong 47 va THUYETMINH_MOPHONG_BEN_CHITIET.md dong 147:
   "600 N theo +Y (phan luc 3 cum canh tay)" dat len 6 lo bat bracket
   (2 lo/canh tay x 3 canh tay) -- run_parts.ps1 dong 20 dat Comp=(0,0,100)
   TUNG lo, tuc 100 N/lo x 6 lo = 600 N tong, KHOP voi 600 N cua tai lieu.
 *** CHUA XAC MINH DUOC NGUON CONG THUC CHINH XAC CUA 600 N ***
   Ca KETQUA_BEN.md va THUYETMINH_MOPHONG_BEN_CHITIET.md chi MO TA dinh
   tinh ("phan luc 3 cum canh tay") ma KHONG co dong cong thuc/phep tinh
   nao dan ra chinh xac con so 600 N (vi du: khong thay lien he truc tiep
   voi FeeMax=175.8N, fMax=122.7N, hay khoi luong canh tay/gearbox nao ra
   dung 600N). Khong tim thay file/log nao khac trong repo giai thich con
   so nay (da rg qua TIENDO.md, ThuyetMinh_LuaChonVatLieu.md, cac file
   faces_DR-001-1*.txt). KHONG bia them cong thuc o day.

--- 5b. DR-001-1 (pose worst-case) ---
 Cong thuc: nhan ty le pose r_pose=fw/fMax len gia tri baseline (khong
   phai tinh rieng, vi phan luc bracket ty le voi luc tay may fMax).
 F = 100.00 N/lo (baseline) x r_pose 1.4867 = 148.67 N/lo
 Doi chieu run_parts_pose.ps1 dong 14 (Comp=149.00 N): KHOP

--- 6. DR-001-2 Khung-Han (khung han, ket cau tinh) ---
 Nguon: KETQUA_BEN.md muc 8.2 (dong 190-202), tinh tay 2026-07-22, CHEP
   LAI nguyen cong thuc, khong tinh lai qua COM trong phien nay:
   m_duoi (CAD, moi thu treo DUOI mat han Y=0, tru DR-001-2/-3) = 89.04 kg
   + hieu chinh mat do gearbox TPMA (CAD 2.354 vs that 8.1 kg/cai x3)  = +17.24 kg
   = m_duoi,that = 89.04 + 17.24 = 106.28 kg
   F = m_duoi,that * g * k_s = 106.28 * 9.81 * 1.5 = 1563.9 N
 Doi chieu run_parts.ps1 / run_parts_pose.ps1: KHONG CO -- DR-001-2 KHONG
   nam trong 2 script nay (chi 5 tag: dr006,dr005b,dr007,dr001_1,dr001_3).
   FEA rieng DR-001-2 chay TRUC TIEP qua fea_run.ps1 (khong qua run_parts*.ps1),
   xem KETQUA_BEN.md muc 8.2. Gia tri F=1563.9N KHOP CHINH XAC voi con so
   "1563,9 N" da ghi trong KETQUA_BEN.md (sai lech 0.010 N do lam tron doc).
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

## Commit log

2026-08-30 Initial commit: Delta robot mechanical design thesis (CAD, kinematics, force analysis, FEA, machining drawings)
    [60645K471_Ball Joint Linkage.SLDPRT, 6516K305_Connecting Rod.SLDPRT, DR-000_Delta-Robot_V0.SLDASM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]
2026-09-01 chore: untrack agent notes, rename folders to English, drop thesis framing in README
    - git rm --cached CLAUDE.md, TIENDO.md and add them to .gitignore
    (local agent working notes, not for publication)
    - rename Vietnamese top-level folders to English and update every path
    reference in scripts (.ps1/.m), docs (.md) and .gitignore:
    BanVe_GiaCong -> MachiningDrawings
    MoPhong_Ben -> FEA_Simulation
    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
    [DR-001-1_De-Gan-Tay.SLDDRW, DR-001-2_Khung-Han.SLDDRW, DR-001-3_Mat-Treo.SLDDRW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]
2026-09-01 docs: add electrical/control-system and machine-vision sections to README
    New README sections 8 (Electrical & control system) and 9 (Machine vision),
    sourced from report chapter 5; the chapter overview table is renumbered to 10.
    - section 8: Siemens motion-control stack (SIMATIC IPC / SIMOTION D /
    SINAMICS S120 x3 / TPMA010S-055T), comms-bus table, hardwired STO
    safety chain, 320 V AC + 24 V DC power; figs 5.6 / 5.7
    - section 9: BGR->HSV colour + shape recognition, HSV threshold table,
    9/9 correct labels on the synthetic test image, camera-base-conveyor
    linear calibration; figs 5.1 / 5.5
    - add 4 figures under docs/figures/ (fig-5-1, fig-5-5, fig-5-6, fig-5-7)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
2026-09-01 docs: add key kinematics equations to README; make folder READMEs consistent
    - README section 1: add geometric model, closed-form inverse kinematics
    (E sinθ + F cosθ + G = 0), forward kinematics (trilateration) and the
    velocity Jacobian / singularity criteria as rendered LaTeX; extend the
    parameter table with R, arm azimuths and the motor-angle range
    - add English README.md to KinematicsSimulation/ and FEA_Simulation/
    (they had none); rewrite ForceAnalysis/ and MachiningDrawings/ READMEs
    in English on the same template (purpose / contents / how to run / key
    results); fix stale refs in MachiningDrawings (v6 -> V7, KIEMTRA path)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
2026-09-01 docs: add vacuum-gripper section to README; drop regenerable run-log clutter
    - README new section 7 "Vacuum gripper (end effector)": suction-force and
    minimum-vacuum sizing (Fs = k m (g+az), S = n pi d^2/4, p_req = Fs/(eta S)),
    worked numbers for 2x Ø40 cups (Fs 85.56 N, p_req 48.7 kPa, hold 105.6 N),
    cup layout by part shape, force diagram fig 2.10; sections 8-11 renumbered
    - untrack 50 regenerable COM-script run logs (MachiningDrawings/log*_*.txt),
    the numbered scratch probe script and a stray docx in FEA_Simulation/, and
    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
